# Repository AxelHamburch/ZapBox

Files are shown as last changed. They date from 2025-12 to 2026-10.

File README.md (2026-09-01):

# Lightning - Zap⚡Box

> **Forked from [danielcharrua/satoffee](https://github.com/danielcharrua/satoffee)**
> Expanded with many new features and hardware for many new use cases.

**A Bitcoin Lightning-controlled switching unit.** Pay an invoice — a relay switches. That's the core idea, and everything else is built on it: vending machines, tip boxes, kiosk terminals, coffee machines, LED signs, servo dispensers.

Ease of use, verifiability and reliability are paramount — all in one package.

📖 Detailed descriptions, images and application examples: [zapbox.space](https://zapbox.space/) · [ereignishorizont.xyz](https://ereignishorizont.xyz/en/zapbox-en/) · [white paper](https://github.com/AxelHamburch/ZapBox/tree/main/assets/white-paper)

---

## Table of Contents

- [How it Works](#how-it-works)
- [Which Variant Do I Need?](#which-variant-do-i-need)
- [Feature Matrix](#feature-matrix)
- [Quick Start](#quick-start)
- [Documentation](#documentation)
- [Development](#development)
- [Compatibility](#compatibility)
- [Acknowledgement](#acknowledgement)
- [Support](#support)

---

## How it Works

1. **QR code** — the display shows a QR code containing the LNURL *(display variants)*
2. **Lightning payment** — the customer scans and pays. Or they tap an **NFC Bolt Card** on the reader, or hold a **smartphone** near the NFC tag — all three routes work
3. **WebSocket trigger** — the LNbits server pushes the payment confirmation to the ESP32
4. **Relay switches** — the output is activated for the configured duration (optionally blinking, pulsing or strobing)
5. **Confirmation** — the display shows the payment was received *(display variants)*

The ZapBox never handles funds itself. It only listens for a confirmation from **your** LNbits server and switches a pin.

---

## Which Variant Do I Need?

Four hardware variants share the same firmware codebase. Pick by **how the customer interacts** with the device:

### 🖥️ [T-Display-S3](docs/t-display-s3.md) — the classic

Small integrated display (170 × 320), optional touch. The most widely deployed ZapBox and the best starting point for most builds.
**4 relay channels** · 2 buttons · optional servo mode · ~150–250 mA

*→ General retail, vending machines, coffee machines, tip boxes*

### 📱 [Touch 3.5"](docs/touch-3.5.md) — the big one

Large 3.5" capacitive touch display (480 × 320). The only variant with a **Mini-PoS mode** (customer-facing amount entry) and a **battery gauge**.
**6 flex channels** · vending sensors · LiPo battery support · ~200–350 mA

*→ Kiosk terminals, market stalls, flea markets, club bars, public vending installations*

### 💡 [Headless ESP32](docs/headless-esp32.md) — the workhorse

No display — status is signalled by a single LED with distinct blink patterns. Has by far the **most channels**.
**12 relay channels** · 2 vending sensors · ~100–150 mA

*→ Embedded and hidden installations, wall-mounted relay control, multi-channel dispensers*

### ⚡ [ESP32-C3](docs/esp32-c3.md) — the small one

Single-core RISC-V, the smallest footprint and the lowest power draw of all variants.
**1 relay + 2 flex channels** · ~80–120 mA

*→ Extremely tight spaces, battery-powered installs, cost-sensitive volume deployments*

---

## Feature Matrix

| | T-Display-S3 | Touch 3.5" | Headless ESP32 | ESP32-C3 |
|---|---|---|---|---|
| **Processor** | ESP32-S3 dual-core | ESP32-S3 dual-core | ESP32 dual-core | ESP32-C3 single-core RISC-V |
| **Display** | LCD 170×320 | Touch 480×320 | — | — |
| **Memory** | 16 MB / 8 MB PSRAM | 16 MB / 8 MB PSRAM | 4 MB / 512 KB | 4 MB / 400 KB |
| **Relay channels** | 4 | 6 | **12** | 1 (+2 flex) |
| **I/O Expander** (+8 channels) | ✅ | — | ✅ | — |
| **Servo mode** | ✅ | ✅ per channel | ✅ | ✅ |
| **Vending sensors** | 1 (light barrier) | 3 | 2 | 2 |
| **NFC** (Bolt Card, phone tap) | ✅ | ✅ | ✅ | ✅ |
| **Identity🫆Login** | LNURL-auth + NFC | LNURL-auth + NFC + PIN | NFC only | — |
| **Mini-PoS** (amount entry) | — | ✅ | — | — |
| **Battery gauge** | — | ✅ | — | — |
| **BTC ticker** | ✅ | ✅ | — | — |
| **Screensaver / Deep Sleep** | ✅ | ✅ | ✅ | ✅ |
| **Power draw** | ~150–250 mA | ~200–350 mA | ~100–150 mA | ~80–120 mA |
| **Firmware suffix** | *(none)* | `t` | `h` | `c` |

---

## Quick Start

1. **Build the hardware** — follow the [electrical layout](docs/hardware-assets.md#electrical-layouts) for your variant
2. **Set up LNbits** — you need a server with the [bitcoinswitch](https://github.com/lnbits/bitcoinswitch) or [zapbox](https://github.com/AxelHamburch/zapbox_extension) extension, and a switch entry per channel
3. **Flash and configure** — open the Web Installer in Chrome or Edge, flash the firmware, then enter WiFi and LNbits settings over the same serial connection

| Variant | Web Installer |
|---|---|
| T-Display-S3 | [installer.zapbox.space](https://installer.zapbox.space/) |
| Touch 3.5" | [installer.zapbox.space/touch3.5/](https://installer.zapbox.space/touch3.5/) |
| Headless ESP32 | [installer.zapbox.space/headless/](https://installer.zapbox.space/headless/) |
| ESP32-C3 | [installer.zapbox.space/c3/](https://installer.zapbox.space/c3/) |

**Entering config mode on an already-flashed device:** hold the BOOT button for 5 seconds.

---

## Documentation

### Hardware variants — pin maps, channels, board-specific features

- 🖥️ **[T-Display-S3](docs/t-display-s3.md)** — GPIO map, 4 channels, servo mode, ambient lighting, light barrier
- 📱 **[Touch 3.5"](docs/touch-3.5.md)** — GPIO map, 6 flex channels, Mini-PoS, battery gauge, vending sensors
- 💡 **[Headless ESP32](docs/headless-esp32.md)** — GPIO map, 12 channels, LED diagnostics, vending sensors
- ⚡ **[ESP32-C3](docs/esp32-c3.md)** — GPIO map, relay + flex channels

### Features across all variants

- 🔧 **[Common Features](docs/common-features.md)** — special modes, BTC ticker, threshold mode, I/O expander, LED button, screensaver & deep sleep, startup & error diagnostics
- 📡 **[NFC](docs/nfc.md)** — Bolt Card payments, card emulation, NT3H2111 phone tap
- 🫆 **[Identity🫆Login](docs/identity.md)** — LNURL-auth and NTAG 424 DNA login without payment

### Hardware & documents

- 🛠️ **[Housings, Layouts & Manuals](docs/hardware-assets.md)** — 3D models, wiring diagrams, operating instructions, QA protocols
- 📦 **[Firmware Release Process](FIRMWARE.md)** — how releases are built

---

## Development

PlatformIO project, Arduino framework, ESP32.

```bash
pio run -e lilygo-t-display-s3    # T-Display-S3
pio run -e Touch3_5               # Touch 3.5"
pio run -e esp32dev               # Headless
pio run -e esp32-c3-21-1          # ESP32-C3
```

**Libraries:** ArduinoJson · OneButton · WebSockets · TFT_eSPI · QRCode

<details>
<summary><strong>Project structure</strong></summary>

```
ZapBox/
├── src/                           # Firmware source (C++)
│   ├── main.cpp                   # Entry point and main event loop
│   ├── API.cpp/h                  # LNbits API & Bitcoin ticker
│   ├── Battery.cpp/h              # Battery gauge (Touch 3.5")
│   ├── Display.cpp/h              # Display rendering (T-Display-S3)
│   ├── DisplayTouch.cpp           # Display rendering (Touch 3.5")
│   ├── DisplayStubs.cpp           # No-op display layer (headless)
│   ├── GlobalState.cpp/h          # Global state & configuration
│   ├── Input.cpp/h                # Button & touch input
│   ├── Navigation.cpp/h           # Screen navigation
│   ├── Network.cpp/h              # WiFi & WebSocket
│   ├── Payment.cpp/h              # Payment processing & LNURL encoding
│   ├── UI.cpp/h                   # UI components
│   ├── NFCPN532.cpp/h             # PN532 NFC reader driver
│   ├── NFCBoltCard.cpp/h          # Bolt Card LNURLW authentication
│   ├── NFCCardEmulation.cpp/h     # PN532 target mode
│   ├── NFCNT3H2111.cpp/h          # NT3H2111 NFC Tag 2 driver
│   ├── IOExpander.h               # PCF8574 (pins 200–207) + PCF8575 (pins 300–315)
│   ├── I2CBus.h                   # Shared I²C bus mutex
│   ├── ServoControl.cpp/h         # Servo motor control
│   ├── TouchCST816S.cpp/h         # Touch driver (T-Display-S3)
│   ├── TouchAXS15231B.cpp/h       # Touch driver (Touch 3.5")
│   ├── SerialConfig.cpp/h         # Serial configuration interface
│   └── PinConfig.h                # Hardware pin definitions (all boards)
├── docs/                          # Documentation (you are here)
├── installer/                     # Web installer & firmware binaries
├── assets/                        # Housings, layouts, manuals, QA
└── platformio.ini                 # Build configuration
```

</details>

---

## Compatibility

- **LNbits**: v1.4.x or higher
- **Bitcoin Switch Extension**: v1.2.1 or higher
- **ZapBox Extension**: required for NFC Bolt Card payments and Mini-PoS — **v2.6.2 or higher** for current firmware (Bolt Card taps and PIN entry ride a persistent device channel; older extensions are served via HTTPS fallback, but the 2.6.0/2.6.1 intermediates must not be mixed with newer firmware)
- **ESP32 classic**: a standard ESP32 works for the headless build — an **unsoldered 30-pin board** is recommended for the headless housing

Software versioning follows the [Releases](https://github.com/AxelHamburch/ZapBox/releases). Housings (`b…`) and electrical layouts (`e…`) are versioned by Bitcoin block height — see [Hardware & Documents](docs/hardware-assets.md).

---

## Acknowledgement

This project is based on Daniel's [SATOFFEE](https://github.com/danielcharrua/satoffee) and uses parts from Ben's [bitcoinswitch](https://github.com/lnbits/bitcoinswitch).

A big thank you goes to [Ben Arc](https://njump.to/nprofile1qqsvrlrhw86l5sv06wkyjgs6rrcekskvk7nx8k50qn9m7mqgeqxjpvgpzamhxue69uhhyetvv9ujumn0wd68ytnzv9hxgtctcf224) and the entire LNbits team for their incredible work.

Parts of this project were developed with the assistance of AI coding assistants (**GitHub Copilot** and **Claude**).

---

## Support

This is a free and open source project. Support is welcome. Making Bitcoin Lightning technology ⚡ accessible to everyone — worldwide. 🌍

<table>
<tr>
<td>
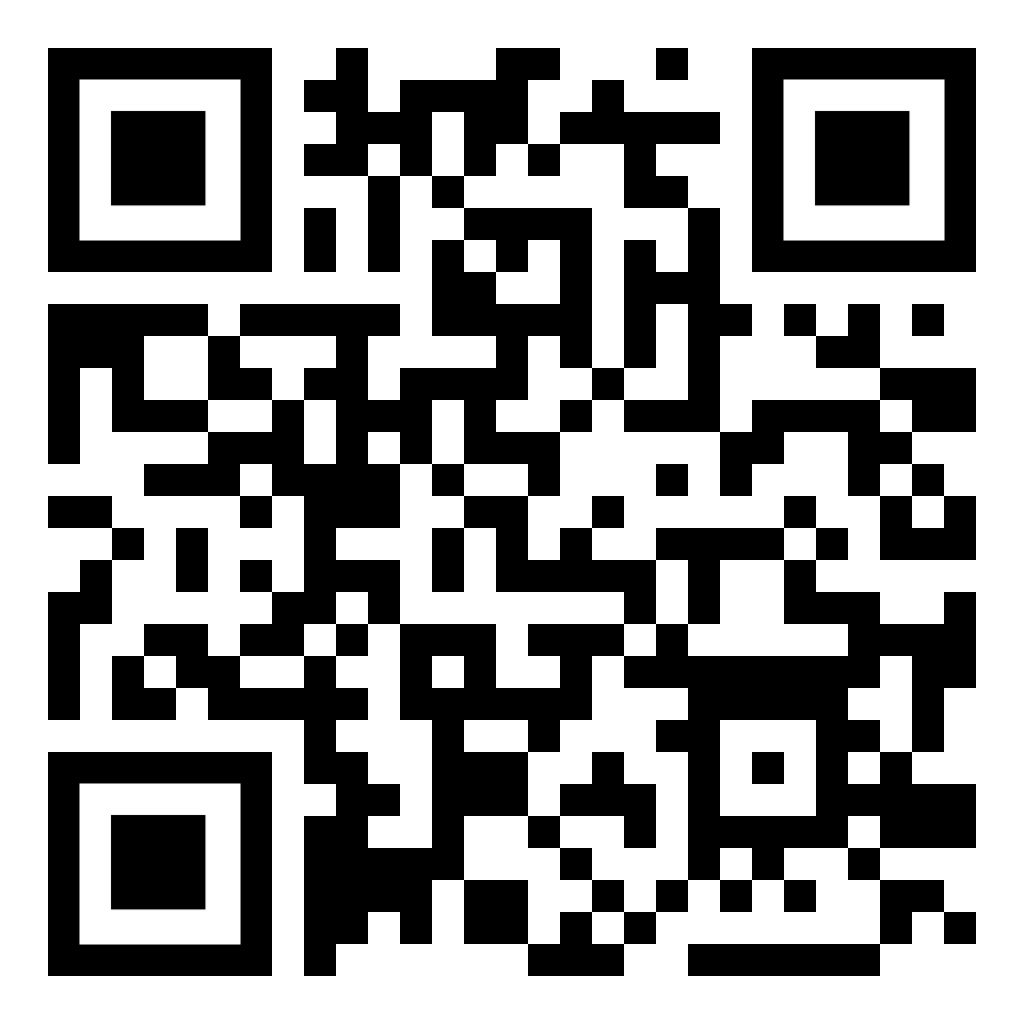
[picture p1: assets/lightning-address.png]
Lightning Address QR Code

</td>
<td>
Lightning⚡Address<br>
axelhamburch@ereignishorizont.xyz
</td>
</tr>
</table>

---

**Lightning ZapBox** — Compact, simple, Bitcoin-powered! ⚡

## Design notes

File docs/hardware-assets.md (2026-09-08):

# Hardware, Housings & Documents

Everything that is not firmware: 3D-printed housings, electrical layouts, operating instructions and QA protocols.

Software versioning follows the [Releases](https://github.com/AxelHamburch/ZapBox/releases). Housings (`b…`) and electrical layouts (`e…`) are versioned by **Bitcoin block height** in the same way.

---

## Table of Contents

- [Electrical Layouts](#electrical-layouts)
- [Housing / 3D Models](#housing--3d-models)
- [Operating Instructions](#operating-instructions)
- [Quality Assurance](#quality-assurance)

---

## Electrical Layouts

Complete wiring diagrams — start here when building a ZapBox.

| Variant | Diagram |
|---|---|
| **Simple** | [E-Layout-ZapBox-Simple.png](../assets/electric/E-Layout-ZapBox-Simple.webp) |
| **Compact** | [E-Layout-ZapBox-Compact.png](../assets/electric/E-Layout-ZapBox-Compact.png) |
| **Compact-Ext** | [E-Layout-ZapBox-Compact-Ext.png](../assets/electric/E-Layout-ZapBox-Compact-Ext.png) |
| **Duo** | [E-Layout-ZapBox-Duo.png](../assets/electric/E-Layout-ZapBox-Duo.png) |
| **Quattro** | [E-Layout-ZapBox-Quattro.png](../assets/electric/E-Layout-ZapBox-Quattro.png) |
| **ZapOMat** | [E-Layout-ZapBox-ZapOMat.png](../assets/electric/E-Layout-ZapBox-ZapOMat.png) |
| **Servo** | [E-Layout-ZapBox-Servo.png](../assets/electric/E-Layout-ZapBox-Servo.png) |
| **Touch 3.5" — ONE** | [E-Layout-ZapBox-Touch3.5-ONE.webp](../assets/electric/E-Layout-ZapBox-Touch3.5-ONE.webp) |
| **Touch 3.5" — FOUR** | [E-Layout-ZapBox-Touch3.5-FOUR.webp](../assets/electric/E-Layout-ZapBox-Touch3.5-FOUR.webp) |
| **Touch 3.5" — SIX+** | [E-Layout-ZapBox-Touch3.5-SIX+.webp](../assets/electric/E-Layout-ZapBox-Touch3.5-SIX+.webp) |
| **Headless** | [E-Layout-ZapBox-Headless.png](../assets/electric/E-Layout-ZapBox-Headless.png) |
| **Headless (S)imple** | [E-Layout-ZapBox-Headless-S.webp](../assets/electric/E-Layout-ZapBox-Headless-S.webp) |
| **Headless Servo** | [E-Layout-ZapBox-Headless-Servo.png](../assets/electric/E-Layout-ZapBox-Headless-Servo.png) |
| **ESP32-C3-21-1** | [E-Layout-ZapBox-esp32-c3-21-1.png](../assets/electric/E-Layout-ZapBox-esp32-c3-21-1.png) |

**Miscellaneous:** [ZapSave](../assets/electric/E-Layout-ZapBox-ZapSave.png) · [USB-Power-Hub](../assets/electric/E-Layout-ZapBox-USB-Power-Hub.png)

### Version history (Inkscape)

| Version | Type | Comment |
|---|---|---|
| e926834 | Compact | Prototype |
| e928304 | Compact | Prototype 2 |
| e928556 | Compact | Sample device |
| e931557 | Duo | First Duo |
| e932547 | Quattro | First Quattro |
| e932714 | Duo | Duo update |
| e935776 | Headless | First Headless |
| e932547 | Quattro | Add update button cable & IR light barrier |
| e937540 | Duo | Duo update |
| e937544 | USB-Power-Hub | First USB-Power-Hub |
| e938714 | ZapOMat | First ZapOMat design |
| e938889 | Headless | Update Headless with ZapBox picture |
| e938897 | Compact | Update Compact with ZapBox picture |
| e939705 | ZapOMat | ZapOMat No.1 |
| e940540 | Headless | Update |
| e943674 | Servo | Start the Servo story |
| e944644 | Headless Servo | First powerful Headless Servo |
| e945370 | ZapOMat | Update with wide-range voltage input |
| e946465 | Servo | Update with wide-range voltage input and NFC plug |
| e947689 | Compact-Ext | Special version with external guided switching contact |
| e948960 | Headless Servo | Add NFC Tag 2 module |
| e948971 | Headless | Add NFC Tag 2 module |
| e949393 | esp32-c3-21-1 | Add special Hans Wurst version |
| e949674 | Servo | Add NFC Tag 2 module & minor redesign |
| e950677 | Compact | Add NFC Tag 2 module |
| e950939 | Touch3.5 | ESP32-S Touch3.5 (JC3248W535C) — prototype |
| e955640 | ZapSave | ZapSave — sample connection |
| e957556 | Touch3.5-FOUR | ZapBox Touch 3.5 with 4 channels |
| e957575 | Touch3.5-ONE | ZapBox Touch 3.5 with 1 channel |
| e958085 | Touch3.5-SIX+ | ZapBox Touch 3.5 with 6 channel & expansion options |
| e959848 | Simple | As simple as possible |
| e965965 | Headless S | First Headless (S)imple |

→ All versions: [assets/electric/](https://github.com/AxelHamburch/ZapBox/tree/main/assets/electric)

---

## Housing / 3D Models

Designed in **FreeCAD**, exported as `.3mf` for printing.

| Version | Type | Comment |
|---|---|---|
| b926837 | Compact | Prototype, uses e926834 |
| b928260 | Compact | Prototype 2, uses e928304 |
| b928555 | Compact | Sample device, uses e928556 |
| b930595 | Compact | Optimization, separate label |
| b931760 | Duo | Prototype Duo with two front panels, 90° and 35° |
| b932506 | Compact | Adapter system, 90° front, USB-C position changed |
| b932595 | Duo & Quattro | Prototype Quattro and Duo update, 90° and 35° front |
| b932788 | Illuminated Sign | Prototype LED sign for demonstration and testing |
| b935750 | Headless | Prototype Headless — ZapBox without display |
| b937454 | USB-Power-Hub | Prototype USB-Power-Hub — voltage distribution only |
| b939002 | Compact | Compact 35° with NFC cap |
| b939704 | ZapOMat | ZapOMat No.1 |
| b940298 | Duo | Update & NFC lid |
| b943400 | Headless | Headless with NFC |
| b943614 | Servo | The first one with servo control |
| b944177 | Headless | Mounting plate with snap-fit connection |
| b944666 | Headless Servo | First powerful Headless Servo |
| b945188 | ZapOMat | Mounting plate and wide-range voltage input |
| b946303 | Servo | Mounting plate and tweaks |
| b946400 | Compact | Mounting plate, 90° NFC and Ext. option |
| b948772 | Headless Servo | Add NFC Tag 2 module |
| b948929 | Headless | Add NFC Tag 2 module |
| b949639 | Servo | Add NFC Tag 2 module |
| b950530 | Compact | Add NFC Tag 2 module |
| b950711 | Touch 3.5 | ESP32-S Touch3.5 (JC3248W535C) No.1 — prototype |
| b955706 | ZapSave | ZapSave — sample box |
| b956540 | Touch3.5-FOUR | ZapBox Touch 3.5 with 4 channels — incl. battery holder |
| b957183 | Touch3.5-ONE | ZapBox Touch 3.5 with 1 channel — incl. battery holder |
| b958015 | Touch3.5-SIX+ | ZapBox Touch 3.5 with 6 channel & expansion options |
| b959898 | Simple | As simple as possible |
| b965887 | Headless S | First Headless (S)imple |

→ All versions: [assets/housing/](https://github.com/AxelHamburch/ZapBox/tree/main/assets/housing)

---

## Operating Instructions

User manuals in Markdown (for reading online) and PDF (for printing).

| | Markdown | PDF |
|---|---|-----|
| **Compact** | [de](../assets/operating-instructions/Compact-oi-de.md) / [en](../assets/operating-instructions/Compact-oi-en.md) | [de](../assets/operating-instructions/Compact-oi-de.pdf) / [en](../assets/operating-instructions/Compact-oi-en.pdf) |
| **Duo** | [de](../assets/operating-instructions/Duo-oi-de.md) / [en](../assets/operating-instructions/Duo-oi-en.md) | [de](../assets/operating-instructions/Duo-oi-de.pdf) / [en](../assets/operating-instructions/Duo-oi-en.pdf) |
| **Quattro** | [de](../assets/operating-instructions/Quattro-oi-de.md) / [en](../assets/operating-instructions/Quattro-oi-en.md) | [de](../assets/operating-instructions/Quattro-oi-de.pdf) / [en](../assets/operating-instructions/Quattro-oi-en.pdf) |
| **ZapOMat** | [de](../assets/operating-instructions/ZapOMat-oi-de.md) / [en](../assets/operating-instructions/ZapOMat-oi-en.md) | [de](../assets/operating-instructions/ZapOMat-oi-de.pdf) / [en](../assets/operating-instructions/ZapOMat-oi-en.pdf) |
| **Servo** | [de](../assets/operating-instructions/Servo-oi-de.md) / [en](../assets/operating-instructions/Servo-oi-en.md) | [de](../assets/operating-instructions/Servo-oi-de.pdf) / [en](../assets/operating-instructions/Servo-oi-en.pdf) |
| **Headless** | [de](../assets/operating-instructions/Headless-oi-de.md) / [en](../assets/operating-instructions/Headless-oi-en.md) | [de](../assets/operating-instructions/Headless-oi-de.pdf) / [en](../assets/operating-instructions/Headless-oi-en.pdf) |
| **Headless Servo** | [de](../assets/operating-instructions/Headless-Servo-oi-de.md) / [en](../assets/operating-instructions/Headless-Servo-oi-en.md) | [de](../assets/operating-instructions/Headless-Servo-oi-de.pdf) / [en](../assets/operating-instructions/Headless-Servo-oi-en.pdf) |

→ Archive and development: [assets/operating-instructions/](https://github.com/AxelHamburch/ZapBox/tree/main/assets/operating-instructions)

---

## Quality Assurance

Templates for QA protocols to ensure ZapBox build quality.

- [Initial Review (German)](../assets/QA/initial-review-de.md) — [PDF](../assets/QA/initial-review-de.pdf)
- [Initial Review (English)](../assets/QA/initial-review-en.md) — [PDF](../assets/QA/initial-review-en.pdf)

→ Archive and development: [assets/QA/](https://github.com/AxelHamburch/ZapBox/tree/main/assets/QA)

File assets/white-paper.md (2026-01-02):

# ZapBox White Paper

**Bitcoin Lightning Network-gesteuerte IoT-Gerätesteuerung**

Version 1.0 | Januar 2026

---

## Abstract

ZapBox ist eine Open-Source-Hardware- und Softwarelösung, die es ermöglicht, physische Geräte über das Bitcoin Lightning Network zu steuern. Durch die Kombination eines ESP32-Mikrocontrollers mit einem Display, Relais und einer WebSocket-basierten Backend-Infrastruktur schafft ZapBox eine Brücke zwischen Kryptowährungszahlungen und realer IoT-Gerätesteuerung. Dieses White Paper beschreibt die technische Architektur, Implementierungsdetails, Anwendungsfälle und die Vision hinter dem Projekt.

---

## Inhaltsverzeichnis

1. [Einleitung](#1-einleitung)
2. [Problemstellung](#2-problemstellung)
3. [Technische Architektur](#3-technische-architektur)
4. [Hardware-Spezifikationen](#4-hardware-spezifikationen)
5. [Backend-Infrastruktur](#5-backend-infrastruktur)
6. [Zahlungsablauf](#6-zahlungsablauf)
7. [Installation und Konfiguration](#7-installation-und-konfiguration)
8. [Betriebsmodi](#8-betriebsmodi)
9. [Sicherheit und Zuverlässigkeit](#9-sicherheit-und-zuverlässigkeit)
10. [Anwendungsfälle](#10-anwendungsfälle)
11. [Produktvarianten](#11-produktvarianten)
12. [Open-Source-Ökosystem](#12-open-source-ökosystem)
13. [Roadmap und Zukunftsperspektiven](#13-roadmap-und-zukunftsperspektiven)
14. [Fazit](#14-fazit)
15. [Referenzen](#15-referenzen)

---

## 1. Einleitung

Die Digitalisierung von Zahlungsprozessen hat in den letzten Jahren erhebliche Fortschritte gemacht. Das Bitcoin Lightning Network bietet als Layer-2-Lösung auf der Bitcoin-Blockchain die Möglichkeit, nahezu kostenfrei und in Echtzeit Mikrotransaktionen durchzuführen. ZapBox nutzt diese Technologie, um eine dezentrale, programmierbare Schnittstelle zwischen digitalen Zahlungen und physischer Gerätesteuerung zu schaffen.

### Vision

**"Wir möchten die Bitcoin-Lightning-Technologie ⚡ für alle zugänglich machen – weltweit. 🌍"**

ZapBox senkt die Einstiegshürden für die Nutzung von Bitcoin Lightning im Internet of Things (IoT) und ermöglicht es jedem – vom Hobbybastler bis zum professionellen Anwender – eigene Lightning-gesteuerte Anwendungen zu realisieren.

---

## 2. Problemstellung

Trotz des enormen Potenzials des Lightning Networks existieren mehrere Barrieren für dessen breite Adoption im IoT-Bereich:

- **Technische Komplexität**: Die Integration von Lightning-Zahlungen in Hardware-Projekte erfordert tiefgreifendes technisches Wissen
- **Fehlende Standardlösungen**: Es gibt wenige fertige Lösungen, die Hardware, Software und Backend integrieren
- **Zugänglichkeit**: Nicht-technische Nutzer können die Technologie nicht ohne weiteres nutzen
- **Hardware-Integration**: Die Verbindung zwischen Zahlungseingang und physischer Aktion ist komplex

ZapBox adressiert diese Herausforderungen durch eine vollständig integrierte, benutzerfreundliche Lösung.

---

## 3. Technische Architektur

### 3.1 Systemübersicht

```
┌─────────────────┐
│  Lightning      │
│  Wallet         │
│  (Nutzer)       │
└────────┬────────┘
         │ QR-Code Scan
         │ LNURL
         ▼
┌─────────────────┐
│  LNbits Server  │
│  + BitcoinSwitch│
│  Extension      │
└────────┬────────┘
         │ WebSocket
         ▼
┌─────────────────┐        ┌──────────────┐
│  ZapBox         │───────►│  Relais      │
│  (ESP32)        │        │  Steuerung   │
└─────────────────┘        └──────────────┘
         │                          │
         ▼                          ▼
┌─────────────────┐        ┌──────────────┐
│  Display        │        │  Externes    │
│  (QR-Code)      │        │  Gerät       │
└─────────────────┘        └──────────────┘
```

### 3.2 Komponenten

**Frontend (Hardware)**
- ESP32 Mikrocontroller
- Display (TFT)
- Touchscreen (CST816S)
- Relais-Modul
- Optionale NFC-Unterstützung (PN532)

**Backend (Software)**
- LNbits Server (Wallet & Account System)
- BitcoinSwitch Extension
- WebSocket-Server für Echtzeitkommunikation

**Kommunikation**
- WiFi (2.4 GHz)
- WebSocket-Protokoll
- LNURL-Standard

---

## 4. Hardware-Spezifikationen

### 4.1 Kern-Komponenten

**Mikrocontroller: ESP32**
- Dual-Core Prozessor (240 MHz)
- 520 KB SRAM
- WiFi 802.11 b/g/n
- Bluetooth (optional nutzbar)
- Geringe Stromaufnahme
- Deep-Sleep-Modus verfügbar

**Display**
- TFT-Display (verschiedene Größen)
- Kapazitiver Touchscreen
- Hochauflösende QR-Code-Darstellung
- Konfigurierbare Farbschemata

**Relais-Modul**
- Schaltspannung: bis 250V AC / 30V DC
- Schaltstrom: bis 10A
- Optionale USB-Buchse (5V)
- Galvanische Trennung

### 4.2 Physisches Design

Die Hardware ist in drei Hauptvarianten verfügbar:

- **ZapBox Compact**: Einzelrelais, kompakte Bauweise
- **ZapBox Duo**: Zwei Relais, davon ein Leistungsrelais mit externen Klemmen
- **ZapBox Quattro**: Vier Relais mit externen Anschlussklemmen für professionelle Anwendungen

Alle Varianten verfügen über:
- 3D-druckbare Gehäuse (FreeCAD-Dateien verfügbar)
- Elektrische Konstruktionsunterlagen
- Stücklisten mit Bezugsquellen

---

## 5. Backend-Infrastruktur

### 5.1 LNbits Server

LNbits ist ein Open-Source Lightning Network Wallet und Account System. Es bietet:

- Multi-User-Wallet-Verwaltung
- Erweiterbare Plugin-Architektur
- REST API
- WebSocket-Support
- Lightning Node Abstraktion

### 5.2 BitcoinSwitch Extension

Die BitcoinSwitch Extension erweitert LNbits um IoT-Steuerungsfunktionalitäten:

- **Device Management**: Verwaltung mehrerer ZapBox-Geräte
- **Invoice Generation**: Automatische Rechnungserstellung
- **WebSocket Bridge**: Echtzeitkommunikation mit Geräten
- **Event Tracking**: Protokollierung aller Schaltvorgänge
- **Multi-Channel Support**: Verwaltung mehrerer Ausgänge pro Gerät

### 5.3 Device String

Jede ZapBox wird durch einen eindeutigen "Device String" identifiziert, der:
- Die Verbindung zum LNbits-Server authentifiziert
- Das spezifische Gerät identifiziert
- Den zu steuernden Ausgang spezifiziert
- In der Firmware konfiguriert wird

---

## 6. Zahlungsablauf

### 6.1 LNURL-Protokoll

Der auf dem Display angezeigte QR-Code verwendet das LNURL-Protokoll (Lightning URL), einen Standard für Lightning Network Interaktionen. Der QR-Code enthält:

1. Server-URL des LNbits-Backends
2. Device-Identifikation
3. Kanal/Ausgangs-Spezifikation
4. Optionale Metadata (Produktname, Preis)

### 6.2 Transaktionsablauf

```
1. ZapBox zeigt QR-Code (LNURL)
   └─> Enthält: Server-URL + Device-ID + Channel

2. Nutzer scannt QR-Code mit Lightning Wallet
   └─> Wallet kontaktiert LNbits Server

3. LNbits prüft WebSocket-Verbindung zur ZapBox
   └─> Bestätigt Geräteverfügbarkeit

4. LNbits generiert Invoice
   └─> Sendet an Wallet mit Betrag & Beschreibung

5. Nutzer bestätigt Zahlung im Wallet
   └─> Lightning-Zahlung wird ausgeführt

6. LNbits bestätigt Zahlungseingang
   └─> Sendet Event über WebSocket an ZapBox

7. ZapBox empfängt Event
   └─> Schaltet Relais für definierte Dauer

8. Relais öffnet/schließt Stromkreis
   └─> Externes Gerät wird aktiviert
```

### 6.3 Timing und Performance

- **Zahlungsbestätigung**: < 1 Sekunde (Lightning)
- **Event-Übertragung**: < 100ms (WebSocket)
- **Relais-Reaktion**: < 50ms
- **Gesamtdauer (Scan bis Schaltung)**: ~1-2 Sekunden

---

## 7. Installation und Konfiguration

### 7.1 Web Installer

ZapBox verwendet einen browserbasierten Installer: **https://installer.zapbox.space/**

Vorteile:
- Keine Software-Installation notwendig
- Plattformunabhängig (Windows, macOS, Linux)
- Nutzt Web Serial API
- Visuelle Feedback während des Flash-Vorgangs

### 7.2 Installationsprozess

**Schritt 1: Firmware-Flash**
1. ZapBox via USB verbinden
2. Web Installer öffnen
3. Firmware-Version auswählen
4. "Flash" Button klicken
5. Warten auf Abschluss

**Schritt 2: Konfiguration**

Pflichtparameter:
- **SSID**: WiFi-Netzwerkname
- **Password**: WiFi-Passwort
- **Device String**: Von LNbits BitcoinSwitch Extension

Optionale Parameter:
- **Display Orientation**: 0°, 90°, 180°, 270°
- **Color Scheme**: Hintergrund- und Textfarben
- **Screensaver**: Aktivierung und Timeout
- **Deep Sleep**: Energiesparmodus
- **Special Modes**: Multi-Channel, Threshold, BTC-Ticker

### 7.3 Ersteinrichtung

Nach dem ersten Boot:
1. ZapBox startet im AP-Modus (falls keine WiFi-Konfiguration)
2. Nutzer verbindet sich mit ZapBox-Access-Point
3. Captive Portal öffnet sich automatisch
4. WiFi und Device-Einstellungen werden eingegeben
5. ZapBox speichert Konfiguration und startet neu
6. Verbindung zum konfigurierten WiFi und LNbits-Server

---

## 8. Betriebsmodi

### 8.1 Standard-Modus

Klassischer Bitcoin-Switch:
- Ein Relais
- Ein Preis pro Zahlung
- Feste Schaltdauer

### 8.2 Multi-Channel-Modus

Mehrere unabhängige Zahlungskanäle:
- Bis zu 4 verschiedene QR-Codes
- Unterschiedliche Preise
- Verschiedene Schaltdauern
- Individuelle Ausgänge

Anwendung: Verkaufsautomat mit mehreren Produkten

### 8.3 Threshold-Modus

Akkumulative Zahlungen:
- Sammelt Zahlungen bis Schwellwert erreicht
- Schaltet erst bei Erreichen des Threshold
- Anzeige des aktuellen Saldos
- Reset nach Schaltung

Anwendung: Crowdfunding-basierte Aktivierung

### 8.4 BTC-Ticker-Modus

Bitcoin-Preis-Display:
- Echtzeit BTC/USD (oder andere Fiat-Währungen)
- Optionale Zahlungsfunktion
- Screensaver mit wechselnden Informationen

Anwendung: Informationsdisplay mit optionaler Spendenfunktion

### 8.5 Special-Modus

Erweiterte Funktionen:
- NFC-Integration (LNURL-NFC-Karten)
- Custom Display-Layouts
- API-Endpunkte für externe Systeme
- Event-Logging

---

## 9. Sicherheit und Zuverlässigkeit

### 9.1 Sicherheitsaspekte

**Netzwerksicherheit**
- TLS/SSL-verschlüsselte WebSocket-Verbindung
- WPA2-geschütztes WiFi
- Keine privaten Schlüssel auf dem Gerät
- Device String als einzige Authentifizierung

**Zahlungssicherheit**
- Lightning Network native Sicherheit
- Atomare Transaktionen
- Keine Rückbuchungen
- Invoice-basiertes System

**Physische Sicherheit**
- Galvanisch getrennte Relais
- Überstromschutz (optional)
- Gehäuse-Design verhindert versehentlichen Zugriff

### 9.2 Zuverlässigkeit

**Fehlerbehandlung**
- Automatische WiFi-Reconnection
- WebSocket-Reconnection mit Backoff
- Watchdog-Timer
- Fehler-Logging auf Display

**Monitoring**
- Verbindungsstatus auf Display
- Letzte Transaktion sichtbar
- Fehler-Codes bei Problemen
- Optional: Remote-Monitoring über LNbits

**Wartung**
- OTA-Updates möglich (zukünftig)
- Config-Reset via Button
- Factory-Reset-Funktion
- Diagnose-Modus

---

## 10. Anwendungsfälle

### 10.1 Kommerzielle Anwendungen

**Verkaufsautomaten**
- Getränkeautomaten
- Snackautomaten
- Waschmaschinen/Trockner in Waschsalons
- Schließfächer

**Zugangskontrollen**
- Türöffner
- Parkplatzschranken
- Ladestationen (E-Bike, E-Scooter)
- Co-Working-Spaces

**Dienstleistungen**
- Luftpumpen an Tankstellen
- Staubsauger an Waschplätzen
- Massagesessel
- Duschen (Campingplätze, Strandbäder)

### 10.2 Bildung und Demonstration

**Workshops**
- Bitcoin-Lightning-Schulungen
- IoT-Entwicklung mit Micropayments
- Maker-Spaces und Hackerspaces

**Ausstellungen**
- Hands-on Lightning-Demonstrationen
- Bitcoin-Konferenzen
- Tech-Messen

### 10.3 Private Nutzung

**Smart Home**
- Lichtsteuerung (Gamification)
- Garagentoröffner für Gäste
- Heimautomation mit Bitcoin-Trigger

**Spiele und Challenges**
- Escape-Room-Rätsel
- Bitcoin-Trivia-Automaten
- Belohnungssysteme

### 10.4 Soziale Projekte

**Crowdfunding**
- Threshold-Modus für Gemeinschaftsprojekte
- Öffentliche Kunstinstallationen
- Charity-Events

**Dezentralisierung**
- P2P-Ressourcenteilung ohne zentrale Verwaltung
- Community-betriebene Infrastruktur

---

## 11. Produktvarianten

### 11.1 ZapBox Compact

**Zielgruppe**: Einsteiger, Hobbyisten

**Spezifikationen**:
- 1 Relais (10A)
- USB-Ausgang (5V/2A)
- Kompaktes Gehäuse
- Eingebaute Antenne
- Touch-Display

**Anwendungen**:
- USB-Gerätesteuerung
- Einzelne Schaltfunktion
- Demonstrationsprojekte

### 11.2 ZapBox Duo

**Zielgruppe**: Ambitionierte Anwender

**Spezifikationen**:
- 2 Relais
- 1 Standard-Relais (10A)
- 1 Leistungsrelais (16A) mit externen Klemmen
- Größeres Gehäuse
- Potentialfreie Kontakte

**Anwendungen**:
- Zwei unabhängige Schaltungen
- Direkte 230V-Schaltung (Leistungsrelais)
- Kombinierte Anwendungen

### 11.3 ZapBox Quattro

**Zielgruppe**: Professionelle Anwendungen

**Spezifikationen**:
- 4 Relais (je 10A)
- Alle Kontakte nach außen geführt
- Professionelle Schraubklemmen
- Robustes Gehäuse
- Optionale DIN-Rail-Montage

**Anwendungen**:
- Verkaufsautomaten
- Komplexe Steuerungen
- Industrielle Integration
- Multi-Produkt-Systeme

### 11.4 Vergleichstabelle

| Eigenschaft | Compact | Duo | Quattro |
|---|---|-----|---|
| Relais | 1 | 2 | 4 |
| Externe Klemmen | Nein | Ja (1x) | Ja (4x) |
| USB-Ausgang | Ja | Optional | Nein |
| Gehäusegröße | Klein | Mittel | Groß |
| Max. Schaltleistung | 2300W | 3680W | 9200W |
| Preissegment | Einstieg | Mittel | Profi |

---

## 12. Open-Source-Ökosystem

### 12.1 Lizenzierung

Alle Komponenten der ZapBox sind vollständig Open Source:

**Hardware**
- Elektrische Schaltpläne: CC BY-SA 4.0
- 3D-Modelle (FreeCAD): CC BY-SA 4.0
- PCB-Layouts: CERN OHL v2

**Software**
- Firmware: MIT License
- Web Installer: MIT License
- Dokumentation: CC BY-SA 4.0

### 12.2 Repository-Struktur

**GitHub Repository**: https://github.com/AxelHamburch/ZapBox

```
ZapBox/
├── src/                    # Firmware-Quellcode
├── assets/                 # Hardware-Designs
│   ├── electric/          # Schaltpläne
│   └── housing/           # Gehäuse-3D-Modelle
├── installer/             # Web Installer
├── lib/                   # Bibliotheken
├── docs/                  # Dokumentation
└── test/                  # Tests
```

### 12.3 Verwendete Open-Source-Projekte

**Backend**:
- **LNbits** (MIT): https://github.com/lnbits/lnbits
- **BitcoinSwitch Extension** (MIT): https://github.com/lnbits/bitcoinswitch_extension

**Firmware-Bibliotheken**:
- ESP32 Arduino Core
- TFT_eSPI (Display)
- ArduinoJson
- WebSocketsClient
- WiFiManager

### 12.4 Community-Beiträge

Das Projekt lebt von Community-Beiträgen:
- Bug Reports und Feature Requests über GitHub Issues
- Pull Requests für Verbesserungen
- Hardware-Varianten und Anpassungen
- Übersetzungen
- Dokumentation

---

## 13. Roadmap und Zukunftsperspektiven

### 13.1 Kurzfristige Ziele (Q1-Q2 2026)

**Firmware**
- OTA-Update-Funktionalität
- Erweiterte NFC-Unterstützung
- Verbesserte Energieverwaltung
- Lokale API für externe Integration

**Hardware**
- ZapBox Quattro Serienproduktion
- Industrielle Variante mit DIN-Rail
- Outdoor-Gehäuse (IP65)

**Software**
- Web Installer v2.0 mit erweiterten Features
- Mobile App für Geräteverwaltung
- Monitoring-Dashboard

### 13.2 Mittelfristige Ziele (Q3-Q4 2026)

**Erweiterungen**
- ZapBox Mini (ohne Display, nur NFC)
- ZapBox Pro (mit integriertem Lightning Node)
- Modular-System für individuelle Konfigurationen

**Integration**
- Home Assistant Integration
- MQTT-Broker-Support
- RESTful API für Third-Party-Apps

**Ökosystem**
- Marketplace für Custom Firmware
- Template-Bibliothek für Anwendungen
- Zertifizierungsprogramm für Partner

### 13.3 Langfristige Vision

**Globale Adoption**
- Entwicklungsländer: Micropayment-Infrastruktur
- Unbanked Populations: Finanzielle Inklusion
- Dezentrale Energiemärkte: P2P-Stromhandel

**Technische Innovation**
- Integration mit RGB Protocol
- Taproot Assets Support
- Lightning-native Smart Contracts

**Standardisierung**
- LNURL-Device-Protocol-Standard
- IoT-Payment-Framework
- Interoperabilität mit anderen Lightning-IoT-Geräten

---

## 14. Fazit

ZapBox repräsentiert einen bedeutenden Schritt in der Verbindung von Bitcoin Lightning Network und dem Internet of Things. Durch die Kombination von benutzerfreundlicher Hardware, robuster Software und einem vollständig Open-Source-Ansatz macht das Projekt Lightning-Zahlungen für physische Anwendungen zugänglich.

### Kernvorteile

1. **Zugänglichkeit**: Senkt technische Hürden drastisch
2. **Dezentralisierung**: Keine zentralen Intermediäre notwendig
3. **Kosten**: Mikrotransaktionen ohne signifikante Gebühren
4. **Geschwindigkeit**: Echtzeit-Zahlungen und -Reaktionen
5. **Open Source**: Vollständige Transparenz und Anpassbarkeit
6. **Skalierbarkeit**: Von Einzelgeräten bis zu großen Installationen

### Bedeutung für das Lightning-Ökosystem

ZapBox demonstriert das Potenzial von Lightning über reine Peer-to-Peer-Zahlungen hinaus. Die Ermöglichung von Machine-to-Machine-Payments und IoT-Integration öffnet neue Anwendungsfelder:

- **Circular Economy**: Bitcoin als natives Zahlungsmittel in automatisierten Systemen
- **Programmable Money**: Zahlungen, die automatisch Aktionen auslösen
- **Micropayment Infrastructure**: Grundlage für pay-per-use Geschäftsmodelle

### Aufruf zur Beteiligung

Das Projekt lädt jeden ein, Teil der Entwicklung zu werden:
- **Entwickler**: Tragen Sie zur Firmware und Software bei
- **Hardware-Designer**: Entwickeln Sie neue Varianten und Gehäuse
- **Anwender**: Teilen Sie Ihre Use Cases und Feedback
- **Unternehmen**: Integrieren Sie ZapBox in Ihre Produkte

**"Jeder soll die ZapBox selbst bauen können. Aber viele werden das gar nicht können oder wollen. Wir möchten die Bitcoin-Lightning-Technologie ⚡ für alle zugänglich machen – weltweit. 🌍"**

---

## 15. Referenzen

### Technische Spezifikationen

- **Lightning Network**: https://lightning.network/
- **LNURL Protocol**: https://github.com/lnurl/luds
- **ESP32 Datasheet**: https://www.espressif.com/en/products/socs/esp32
- **Bitcoin Switch (Ben Arc)**: Original Konzept und Inspiration

### Open-Source-Projekte

- **ZapBox GitHub**: https://github.com/AxelHamburch/ZapBox
- **LNbits**: https://github.com/lnbits/lnbits
- **BitcoinSwitch Extension**: https://github.com/lnbits/bitcoinswitch_extension

### Weiterführende Informationen

- **ZapBox Website**: https://zapbox.space/
- **Web Installer**: https://installer.zapbox.space/
- **Community Forum**: (In Entwicklung)
- **Documentation**: https://github.com/AxelHamburch/ZapBox/wiki

### Kontakt

- **GitHub**: https://github.com/AxelHamburch
- **Repository Issues**: https://github.com/AxelHamburch/ZapBox/issues
- **Email**: (Über GitHub-Profile)

---

## Anhang A: Technische Glossar

- **ESP32**: Mikrocontroller von Espressif mit WiFi und Bluetooth
- **Lightning Network**: Layer-2-Protokoll für schnelle Bitcoin-Transaktionen
- **LNURL**: Lightning URL Protocol für vereinfachte Interaktionen
- **Invoice**: Lightning-Rechnung für eine Zahlung
- **WebSocket**: Bidirektionales Kommunikationsprotokoll
- **Relais**: Elektromechanischer Schalter
- **OTA**: Over-The-Air (drahtlose Firmware-Updates)
- **FOSS**: Free and Open Source Software

---

## Anhang B: Elektrische Spezifikationen

### Relais-Spezifikationen

**Standard-Relais (Compact, Duo, Quattro)**
- Kontakttyp: SPDT (Single Pole Double Throw)
- Nennspannung: 250V AC / 30V DC
- Nennstrom: 10A
- Schaltleistung: 2500VA / 300W
- Lebensdauer: >100.000 Zyklen

**Leistungsrelais (Duo)**
- Kontakttyp: SPDT
- Nennspannung: 250V AC / 30V DC
- Nennstrom: 16A
- Schaltleistung: 4000VA / 480W
- Lebensdauer: >50.000 Zyklen

### Stromversorgung

- Eingangsspannung: 5V DC via USB-C
- Stromaufnahme: 150-500mA (je nach Display-Helligkeit)
- Deep Sleep: <10mA
- Empfohlenes Netzteil: 5V/2A

---

## Anhang C: Versionierung

**Firmware-Versionen**:
- v9.x.x: Aktuelle Hauptversion
- Semantische Versionierung (MAJOR.MINOR.PATCH)
- Release Notes im GitHub Repository

**Hardware-Revisionen**:
- Elektrische Schemata: eXXXXXX-compact
- Gehäuse: bXXXXXX-compact
- Vollständige History in Git

---

*Dieses Dokument wurde am 2. Januar 2026 erstellt und wird regelmäßig aktualisiert. Die neueste Version ist stets im GitHub-Repository verfügbar.*

---

**ZapBox - Open Source Bitcoin Lightning IoT**

⚡ Powered by the Lightning Network | 🌍 Available Worldwide | 🔓 Fully Open Source

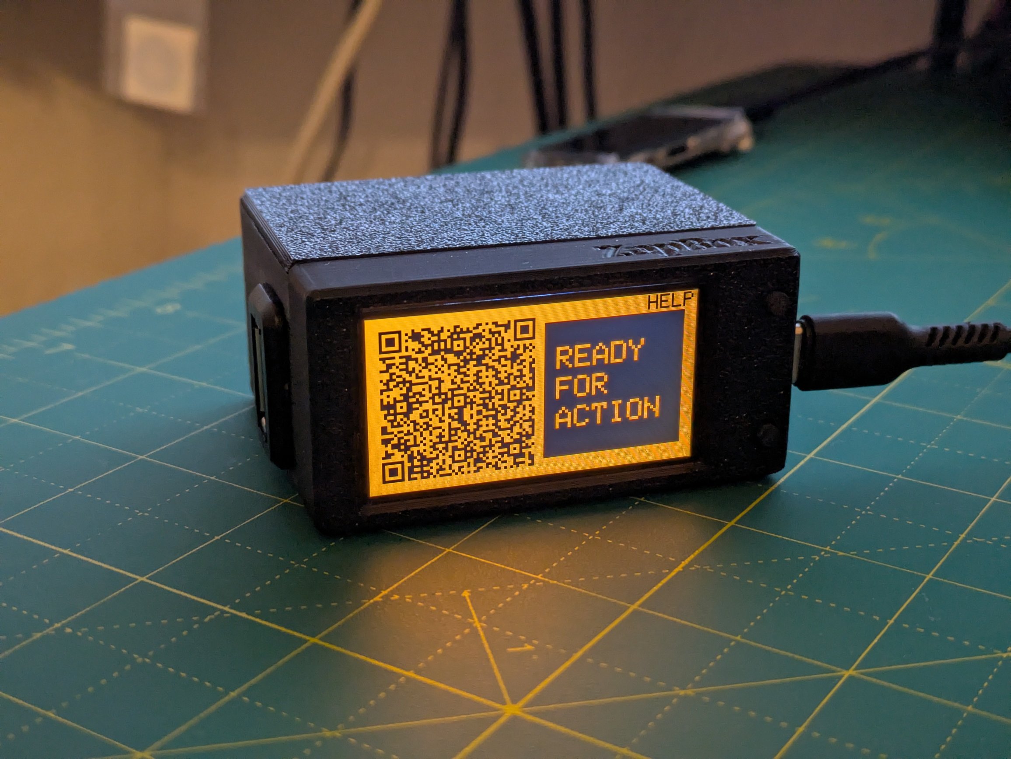
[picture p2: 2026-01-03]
assets/white-paper/ZapBox_no001.jpg

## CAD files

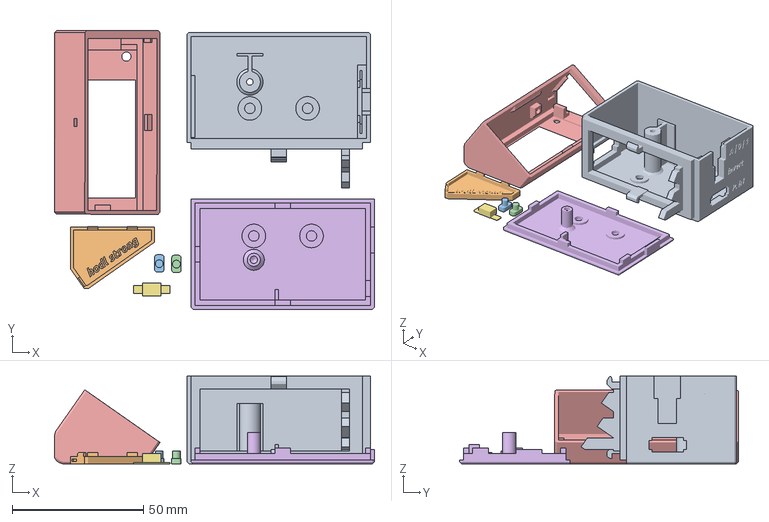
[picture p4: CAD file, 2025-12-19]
assets/housing/b928260-ompact/ZapBox Compact - b928260 full.3mf
122.0 x 106.3 x 33.5 mm

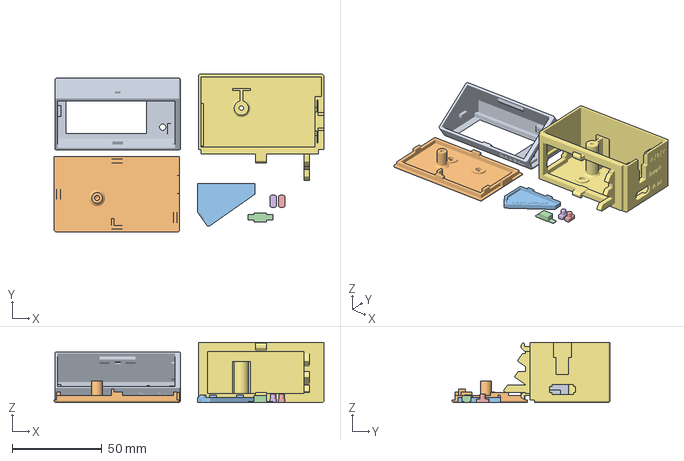
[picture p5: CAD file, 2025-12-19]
assets/housing/b928555-ompact/ZapBox Compact - b928555-full.3mf
150.3 x 87.9 x 33.5 mm

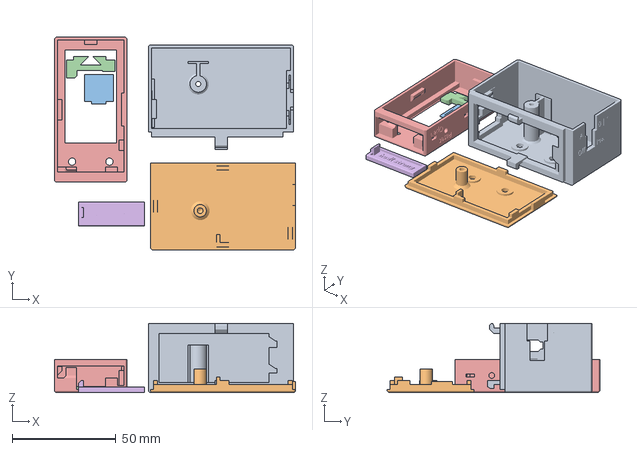
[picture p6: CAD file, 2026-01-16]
assets/housing/b932506-Compact/ZapBox Compact - b932506 - full - 90 degree.3mf
116.3 x 102.7 x 33.5 mm

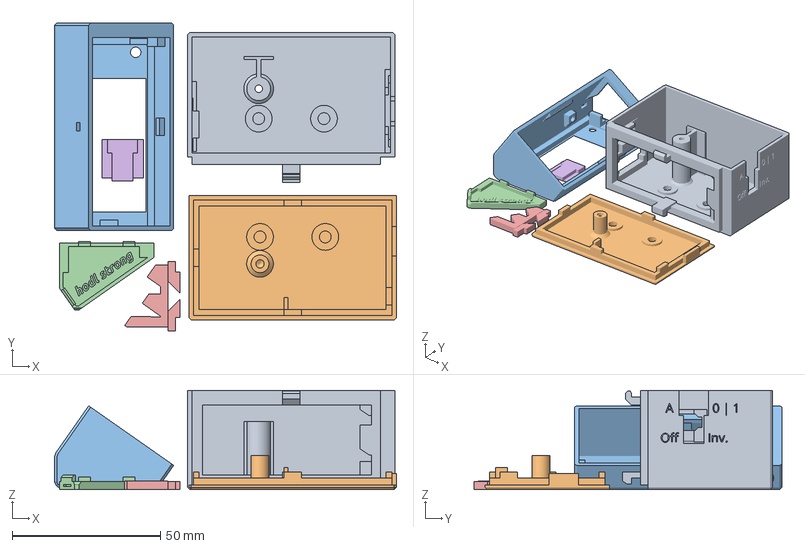
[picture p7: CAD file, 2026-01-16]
assets/housing/b932506-Compact/ZapBox Compact - b932506 - full - 35 degree.3mf
115.3 x 103.9 x 33.5 mm

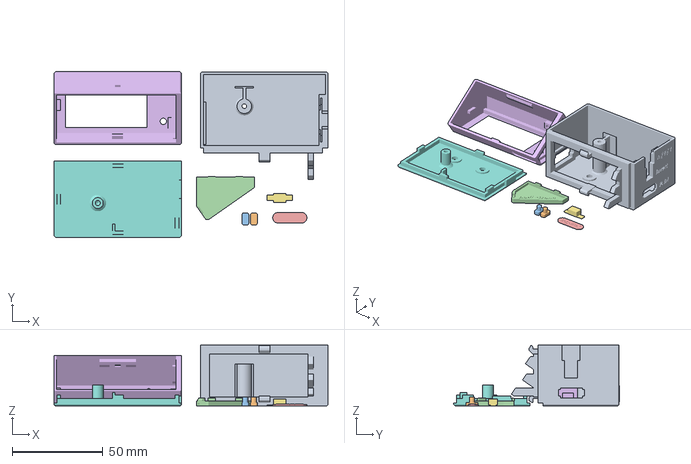
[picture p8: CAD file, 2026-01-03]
assets/housing/b930595-ompact/ZapBox Compact - b930595-Full.3mf
150.6 x 91.2 x 33.5 mm

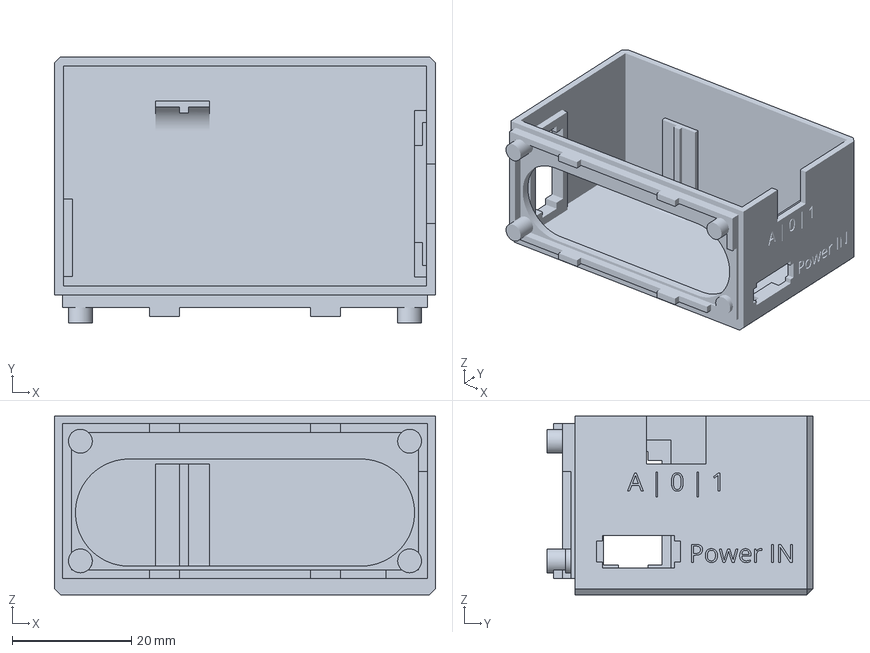
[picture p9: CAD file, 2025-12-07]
assets/housing/b926837-Compact/ZapBox Compact - v0.07-Grundkörper.3mf
64.0 x 44.7 x 30.0 mm

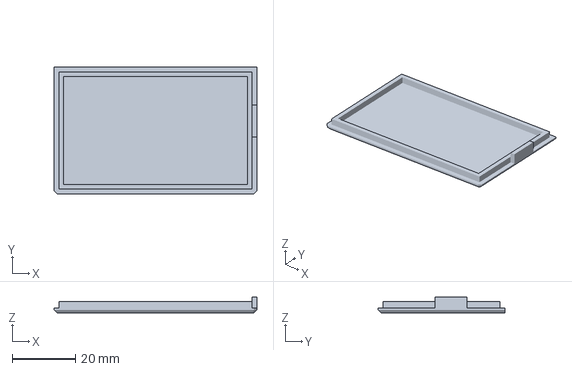
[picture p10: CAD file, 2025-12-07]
assets/housing/b926837-ompact/ZapBox Compact - v0.07-Deckel.3mf
64.0 x 40.0 x 5.00 mm

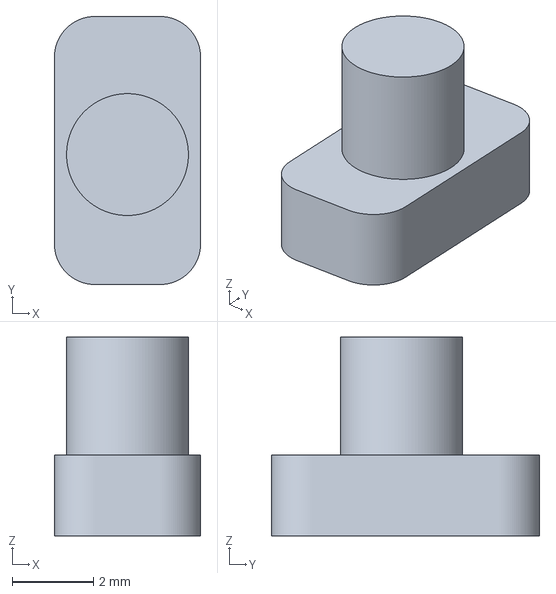
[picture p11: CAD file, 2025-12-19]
assets/housing/b928260-Compact/ZapBox Compact - b928260-Button (Solid).3mf
3.60 x 6.60 x 4.90 mm

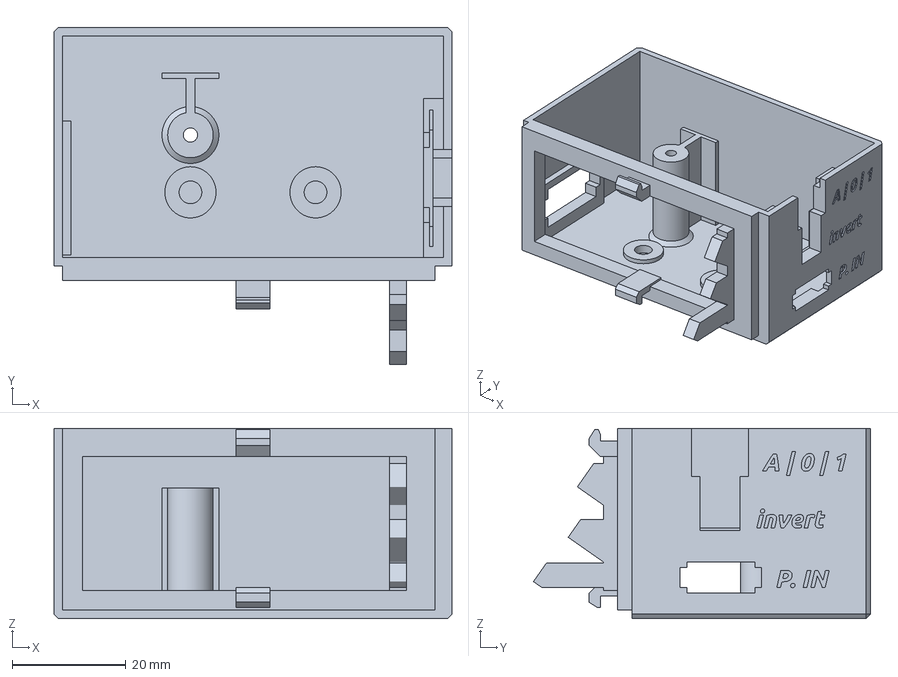
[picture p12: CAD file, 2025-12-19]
assets/housing/b928555-Compact/ZapBox Compact - b928555-Chamfer025 Chamber.3mf
70.0 x 59.3 x 33.5 mm

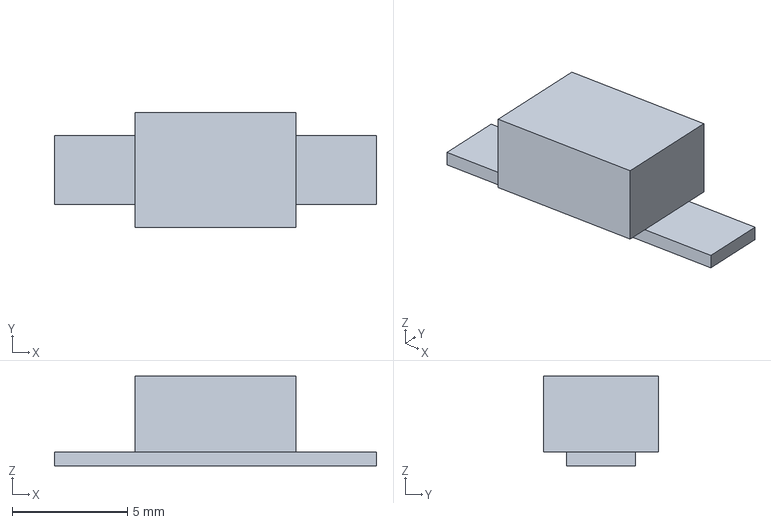
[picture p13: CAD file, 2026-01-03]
assets/housing/b930595-ompact/ZapBox Compact - b930595-Switch Spacer (Solid).3mf
14.0 x 5.00 x 3.90 mm

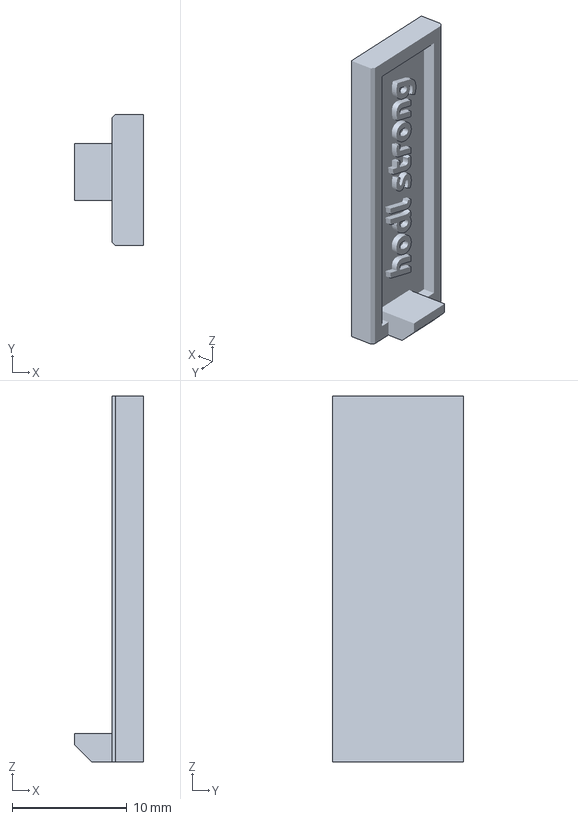
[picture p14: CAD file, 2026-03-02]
assets/housing/b939002-Compact/ZapBox Compact - b939002-Panel 90 degree.3mf
6.00 x 11.4 x 31.9 mm

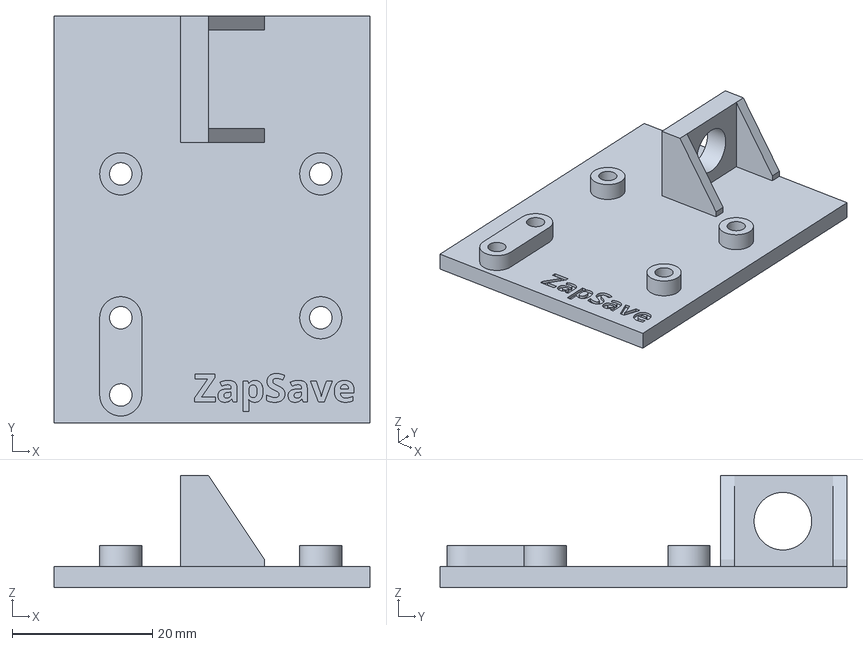
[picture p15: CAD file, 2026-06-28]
assets/housing/b955706-ZapSave/ZapSave - b955706-Circuit board.3mf
45.0 x 58.0 x 16.0 mm

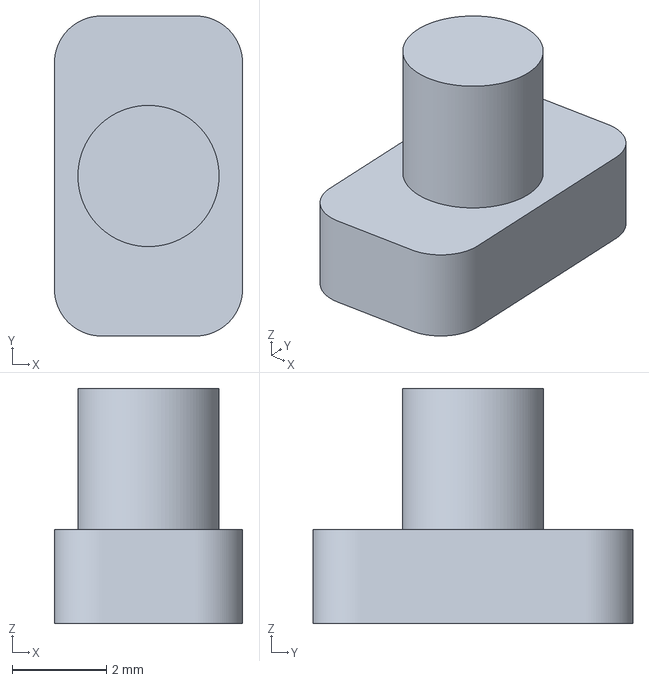
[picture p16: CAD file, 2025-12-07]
assets/housing/b926837-ompact/ZapBox Compact - v0.07-Taste.3mf
4.00 x 6.80 x 5.00 mm

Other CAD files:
assets/housing/b930595-Compact/ZapBox Compact - b930595-Chamfer Chamber.3mf
assets/housing/b926837-Compact/ZapBox Compact - v0.07-Front.3mf
assets/housing/b926837-ompact/ZapBox Compact - v0.07-Front.3mf
assets/housing/b928260-Compact/ZapBox Compact - b928260-Access Panel (Solid).3mf
assets/housing/b928260-Compact/ZapBox Compact - b928260-Chamfer Chamber.3mf
assets/housing/b928260-Compact/ZapBox Compact - b928260-Chamfer Front.3mf
assets/housing/b928260-Compact/ZapBox Compact - b928260-Chamfer Lid.3mf
assets/housing/b928260-Compact/ZapBox Compact - b928260-Switch Spacer (Solid).3mf
assets/housing/b928260-ompact/ZapBox Compact - b928260-Access Panel (Solid).3mf
assets/housing/b928260-ompact/ZapBox Compact - b928260-Chamfer Chamber.3mf
assets/housing/b928260-ompact/ZapBox Compact - b928260-Chamfer Front.3mf
assets/housing/b928260-ompact/ZapBox Compact - b928260-Chamfer Lid.3mf
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

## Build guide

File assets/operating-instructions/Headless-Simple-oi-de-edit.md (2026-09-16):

# ZapBox Headless Simple – Bedienungsanleitung

**Sprache:** Deutsch | **Version:** oi967253
---
## Inhaltsverzeichnis

1. [Übersicht](#übersicht)
2. [Ansichten](#ansichten)
3. [Anschlüsse](#anschlüsse)
4. [Bedienelemente](#bedienelemente)
5. [Einrichtung und Inbetriebnahme](#einrichtung-und-inbetriebnahme)
6. [Technische Daten](#technische-daten)
7. [Sicherheitshinweise](#sicherheitshinweise)
8. [Weiterführende Links](#weiterführende-links)

---

## Übersicht

Die **ZapBox Headless Simple** ist ein elektronischer Schalter für Bitcoin-Lightning-Zahlungen ohne Display. Mit einer Zahlung über das Lightning-Netzwerk lässt sich ein Ausgang schalten – ideal für eingebettete Anwendungen, verdeckte Installationen, Maschinenbau und überall dort, wo kein Display benötigt wird.

Der Betriebszustand wird ausschließlich über eine **Status-LED** angezeigt. Eine zweite **Action-LED** zeigt die Schaltfunktion an.

### Grundausstattung

| Komponente | Beschreibung |
|---|---|
| Mikrocontroller | ESP32 Dev Module (kein Display) |
| Eingang | Dual USB-A und USB-C |
| Ausgang | Dual USB-A und USB-C |
| Statusanzeige | Status-LED mit Blinkmustern und Action-LED als Rückmeldung |
| Bedienelement | Mikrotaster für BOOT (Config-Modus) und Reset |

## Ansichten

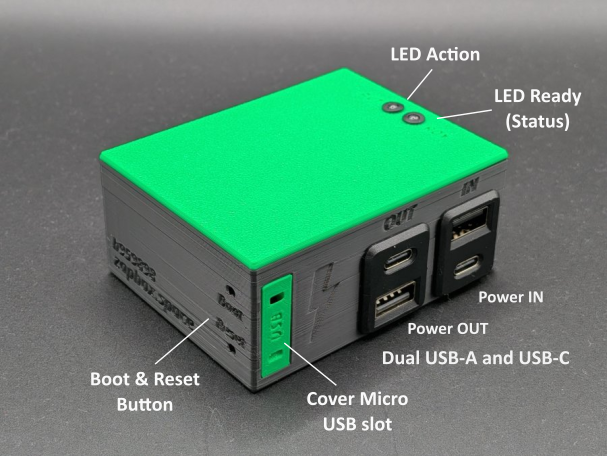
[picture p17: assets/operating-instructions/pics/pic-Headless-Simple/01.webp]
Dreiseitenansicht


*Bild 1: Dreiseitenansicht*

---

## Anschlüsse

### Eingang - Dual USB-A und USB-C Buchse zur Spannungsversorgung (5V)

Versorgen Sie das Gerät über den Anschluss **Power IN** mit einem USB-C-Kabel mit **5 V DC (max. 5 A)**.

> **Hinweis:** Der USB-Power-Anschluss unterstützt keine automatische USB-C-Leistungsanforderung (kein USB-C Power Delivery). Einige USB-C-Ladegeräte oder Powermodule erkennen die ZapBox daher nicht als Verbraucher und liefern keinen Strom. Verwenden Sie in diesem Fall einen **USB-A-Ausgang** der Spannungsversorgung oder eine alternative 5-V-Stromquelle. Die maximale Stromstärke darf 3 A nicht überschreiten.

### Eingang - Micro-USB Buchse am Mikrocontroller (Datenzugang, seitlich)

Um Daten vom Gerät zu lesen oder zu übertragen, verbinden Sie die ZapBox mit einem Computer oder Laptop:

1. An der **rechten Seite**, neben den USB-Anschlüssen, befindet sich ein kleines Panel. Öffnen Sie das Panel mit einem **schmalen Schraubendreher**, indem Sie es vorsichtig herausheben.
2. Schließen Sie ein Micro-USB-Kabel an den Mikrocontroller an.

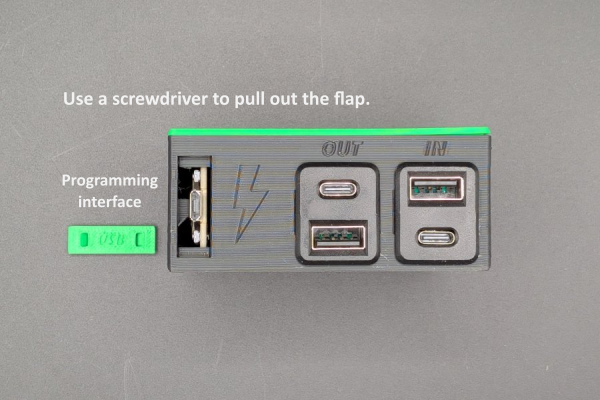
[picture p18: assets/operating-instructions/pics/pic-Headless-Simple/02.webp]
Micro USB Port


*Bild 2: Micro USB Port*

> **Wichtiger Hinweis:** Der USB-Anschluss direkt am Mikrocontroller ist ausschließlich zum Flashen der Firmware und zur Übertragung von Konfigurationsparametern vorgesehen. Während des Flashvorgangs darf keine Last am Ausgang angeschlossen oder geschaltet werden, da dies zu Fehlfunktionen oder zur **Beschädigung des Mikrocontrollers** führen kann.
>
> Es wird daher empfohlen:
> - während der USB-Verbindung keine Last am Ausgang anzuschließen oder
> - den regulären **Power-IN-Eingang** zusätzlich an dieselbe Spannungsversorgung anzuschließen. Dadurch wird sichergestellt, dass der Strom für das Leistungsrelais nicht über den Mikrocontroller fließt und diesen überlastet.

### Ausgang - Dual USB-A und USB-C Buchse (geschaltete 5V Spannung)

Die USB-Buchse wird über einen Relais-Schaltkontakt geschaltet. Die **Gesamtbelastung** der Buchsen sollte **3 A nicht überschreiten**.

---

## Bedienelemente

Die ZapBox Headless hat **kein Display**. Der Betriebszustand wird ausschließlich über die **Status-LED** (GPIO 21 (extern) / GPIO 2 (onboard)) und **Action-LED** (GPIO 13) signalisiert.

### Status-LED – Blinkmuster

| Muster | Bedeutung |
|---|---|
| 3× kurzes Blinken beim Start | Boot abgeschlossen |
| Schnelles Blinken | Verbindungsaufbau / Initialisierung |
| Langsames Blinken (1 Hz) | Config-Modus aktiv |
| Dauerlicht | Betriebsbereit, wartet auf Zahlung |
| Kurzes Ausschalten (300 ms) | Aktion gestartet – Relais/Servo ausgelöst |
| 200 ms an / 800 ms aus | NFC-Zahlung ausstehend (PENDING) |
| 2× kurzes Blinken | Zahlung erfolgreich |
| 3× kurzes Blinken | NFC-Timeout / Fehler |
| 1× Blinken (500 ms an/aus, 2 s Pause) | Fehlermuster 1: Kein WLAN |
| 2× Blinken (300 ms an/aus, 2 s Pause) | Fehlermuster 2: Kein Internet |
| 3× Blinken (250 ms an/aus, 2 s Pause) | Fehlermuster 3: Server nicht erreichbar |
| 4× Blinken (200 ms an/aus, 2 s Pause) | Fehlermuster 4: WebSocket-Verbindung fehlgeschlagen |

### Bedientaster

| Funktion | Taster |
|---|---|
| Config-Modus aufrufen | BOOT-Taster mind. 5 Sek. gedrückt halten |
| Neustart | Reset-Taster |

---

## Einrichtung und Inbetriebnahme

Die ZapBox wird nach der Fertigung getestet und mit der aktuellen Firmware ausgeliefert - sie ist aber nicht parametriert. Die Software wird aktiv weiterentwickelt, daher ist es empfehlenswert, die ZapBox gleich zu Beginn einmal mit der neuesten Firmware zu bespielen und dann eine Parametrierung durchzuführen. Dafür gibt es einen komfortablen [**Web-Installer Headless**](https://installer.zapbox.space/headless/).

### Schritt 1: Firmware-Update
1. Öffnet auf der rechten Seite das Panel, wie oben unter "Eingang - Micro-USB Buchse am Mikrocontroller" beschrieben.
2. Schließt die ZapBox an dem USB-C-Port mit einem Kabel an und verbindet es mit einem Computer.
3. Öffnet einen Chromium Browser, zum Beispiel Google Chrome, Microsoft Edge, Brave, Vivaldi, Opera oder [Helium](https://helium.computer/).

### Schritt 2: Parametrierung
1. Navigiert im Browser zur Web-Installer-Seite.
2. Folgt den Anweisungen auf der Seite, um die gewünschten Parameter wie `WiFi SSID`, `WiFi Passwort` und `Device Settings String` einzugeben.
3. Speichert die Einstellungen und startet die ZapBox neu.

> **Hinweis:** Während der Einrichtung sollte keine Last an den Ausgängen angeschlossen sein, um Fehlfunktionen oder Schäden am Mikrocontroller zu vermeiden.

Die ZapBox wird nach der Initialisierung den QR-Code des Produkts anzeigen und ist bereit für die erste Zahlung und anschließende Schaltaktion.

---

## Technische Daten

| Eigenschaft | Wert |
|---|---|
| Versorgungsspannung | 5 V DC über USB-C |
| Maximaler Eingangsstrom | 5,0 A |
| Ausgangsleistung | max. 3,0 A (empfohlen) |
| Mikrocontroller | ESP32 Dev Module (WROOM-32) |
| Display | keines (Headless) |
| Statusanzeige | Status-LED / Action-LED |
| Temperaturbereich | 0–40 °C |
| Kommunikation | Wi-Fi (ESP32) |
| Zahlungsprotokoll | Bitcoin Lightning Network |

---

## Sicherheitshinweise

- Betreiben Sie das Gerät ausschließlich mit der angegebenen Versorgungsspannung.
- Überschreiten Sie nicht die maximalen Strombelastungen der Ausgänge.
- Führen Sie keine Arbeiten an den Relaiskontakten unter Last durch.
- Das Gerät ist nicht für den Einsatz in feuchten oder nassen Umgebungen geeignet.
- Sorgen Sie für ausreichende Belüftung um das Gerät.
- Außerhalb der Reichweite von Kindern aufbewahren.

---

## Weiterführende Links

| Ressource | Link |
|---|---|
| Übersicht aller ZapBox-Modelle | https://zapbox.space/ |
| Web-Installer, Kurzübersicht & Fehlerbehebung | https://installer.zapbox.space/ |
| Detaillierte Dokumentation (Parameter & Funktionen) | https://ereignishorizont.xyz/zapbox/ |
| GitHub-Repository (Software, E-Layouts, 3D-Druckdateien, Bedienungsanleitungen, etc.) | https://github.com/AxelHamburch/ZapBox |
| ZapBox Extension | https://github.com/AxelHamburch/zapbox_extension |
| LNbits | https://lnbits.com/ |

---

*Änderungen und Irrtümer vorbehalten. Stand: 2026*

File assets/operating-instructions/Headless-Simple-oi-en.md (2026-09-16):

# ZapBox Headless Simple – Operating Instructions

**Language:** English | **Version:** oi967253
---
## Table of Contents

1. [Overview](#overview)
2. [Views](#views)
3. [Connections](#connections)
4. [Controls](#controls)
5. [Setup and Commissioning](#setup-and-commissioning)
6. [Technical Data](#technical-data)
7. [Safety Instructions](#safety-instructions)
8. [Further Links](#further-links)

---

## Overview

The **ZapBox Headless Simple** is an electronic switch for Bitcoin Lightning payments without a display. A payment via the Lightning Network can be used to switch an output – ideal for embedded applications, concealed installations, machine building, and anywhere a display is not needed.

The operating state is indicated exclusively via a **status LED**. A second **action LED** indicates the switching function.

### Basic Equipment

| Component | Description |
|---|---|
| Microcontroller | ESP32 Dev Module (no display) |
| Input | Dual USB-A and USB-C |
| Output | Dual USB-A and USB-C |
| Status display | Status LED with blink patterns and action LED as feedback |
| Control | Micro switch for BOOT (config mode) and reset |

## Views

Three-side view

*Figure 1: Three-side view*

---

## Connections

### Input - Dual USB-A and USB-C socket for power supply (5V)

Power the device via the **Power IN** connector using a USB-C cable with **5 V DC (max. 5 A)**.

> **Note:** The USB power connector does not support automatic USB-C power negotiation (no USB-C Power Delivery). Some USB-C chargers or power modules therefore do not recognize the ZapBox as a load and will not supply power. In this case, use a **USB-A output** of the power supply or an alternative 5 V power source. The maximum current must not exceed 3 A.

### Input - Micro-USB socket on the microcontroller (data access, on the side)

To read or transfer data from the device, connect the ZapBox to a computer or laptop:

1. On the **right side**, next to the USB connectors, there is a small panel. Open the panel with a **narrow screwdriver** by carefully prying it out.
2. Connect a Micro-USB cable to the microcontroller.

Micro USB Port

*Figure 2: Micro USB Port*

> **Important note:** The USB connector directly on the microcontroller is intended exclusively for flashing the firmware and transferring configuration parameters. During the flashing process, no load may be connected or switched at the output, as this can lead to malfunctions or **damage to the microcontroller**.
>
> It is therefore recommended to either:
> - not connect any load at the output while the USB connection is active, or
> - additionally connect the regular **Power-IN input** to the same power supply. This ensures that the current for the power relay does not flow through the microcontroller and overload it.

### Output - Dual USB-A and USB-C socket (switched 5V voltage)

The USB sockets are switched via a relay contact. The **total load** of the sockets should **not exceed 3 A**.

---

## Controls

The ZapBox Headless has **no display**. The operating state is signaled exclusively via the **status LED** (GPIO 21 (external) / GPIO 2 (onboard)) and **action LED** (GPIO 13).

### Status LED – Blink Patterns

| Pattern | Meaning |
|---|---|
| 3× short blink on start | Boot complete |
| Fast blinking | Connecting / initializing |
| Slow blinking (1 Hz) | Config mode active |
| Steady light | Ready for operation, waiting for payment |
| Short off (300 ms) | Action started – relay/servo triggered |
| 200 ms on / 800 ms off | NFC payment pending (PENDING) |
| 2× short blink | Payment successful |
| 3× short blink | NFC timeout / error |
| 1× blink (500 ms on/off, 2 s pause) | Error pattern 1: No WiFi |
| 2× blink (300 ms on/off, 2 s pause) | Error pattern 2: No internet |
| 3× blink (250 ms on/off, 2 s pause) | Error pattern 3: Server unreachable |
| 4× blink (200 ms on/off, 2 s pause) | Error pattern 4: WebSocket connection failed |

### Control Buttons

| Function | Button |
|---|---|
| Open config mode | Hold BOOT button for at least 5 sec. |
| Restart | Reset button |

---

## Setup and Commissioning

The ZapBox is tested after manufacturing and shipped with the current firmware - however, it is not yet parameterized. The software is under active development, so it is recommended to flash the ZapBox with the latest firmware right at the start and then perform the parameterization. A convenient [**Web Installer Headless**](https://installer.zapbox.space/headless/) is available for this.

### Step 1: Firmware Update
1. Open the panel on the right side, as described above under "Input - Micro-USB socket on the microcontroller".
2. Connect the ZapBox to the USB-C port with a cable and connect it to a computer.
3. Open a Chromium browser, for example Google Chrome, Microsoft Edge, Brave, Vivaldi, Opera, or [Helium](https://helium.computer/).

### Step 2: Parameterization
1. Navigate to the Web Installer page in the browser.
2. Follow the instructions on the page to enter the desired parameters such as `WiFi SSID`, `WiFi password`, and `Device Settings String`.
3. Save the settings and restart the ZapBox.

> **Note:** No load should be connected to the outputs during setup, to avoid malfunctions or damage to the microcontroller.

After initialization, the ZapBox will display the product's QR code and is ready for the first payment and subsequent switching action.

---

## Technical Data

| Property | Value |
|---|---|
| Supply voltage | 5 V DC via USB-C |
| Maximum input current | 5.0 A |
| Output power | max. 3.0 A (recommended) |
| Microcontroller | ESP32 Dev Module (WROOM-32) |
| Display | none (headless) |
| Status display | Status LED / action LED |
| Temperature range | 0–40 °C |
| Communication | Wi-Fi (ESP32) |
| Payment protocol | Bitcoin Lightning Network |

---

## Safety Instructions

- Operate the device only with the specified supply voltage.
- Do not exceed the maximum current load of the outputs.
- Do not perform any work on the relay contacts under load.
- The device is not suitable for use in damp or wet environments.
- Ensure adequate ventilation around the device.
- Keep out of the reach of children.

---

## Further Links

| Resource | Link |
|---|---|
| Overview of all ZapBox models | https://zapbox.space/ |
| Web Installer, quick overview & troubleshooting | https://installer.zapbox.space/ |
| Detailed documentation (parameters & functions) | https://ereignishorizont.xyz/zapbox/ |
| GitHub repository (software, PCB layouts, 3D print files, operating instructions, etc.) | https://github.com/AxelHamburch/ZapBox |
| ZapBox Extension | https://github.com/AxelHamburch/zapbox_extension |
| LNbits | https://lnbits.com/ |

---

*Subject to changes and errors. As of: 2026*

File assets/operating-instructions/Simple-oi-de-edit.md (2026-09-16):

# ZapBox Simple – Bedienungsanleitung

**Sprache:** Deutsch | **Version:** oi967281

---

## Inhaltsverzeichnis

1. [Übersicht](#übersicht)
2. [Ansichten](#ansichten)
3. [Anschlüsse](#anschlüsse)
4. [Bedienelemente](#bedienelemente)
5. [Einrichtung und Inbetriebnahme](#einrichtung-und-inbetriebnahme)
6. [Technische Daten](#technische-daten)
7. [Sicherheitshinweise](#sicherheitshinweise)
8. [Weiterführende Links](#weiterführende-links)

---

## Übersicht

Die **ZapBox Compact** ist ein elektronischer Schalter für Bitcoin-Lightning-Zahlungen. Mit einer Zahlung über das Lightning-Netzwerk lässt sich ein Ausgang schalten – ideal für Automaten, Präsentationen, Eventsteuerung und viele weitere Anwendungen.

### Grundausstattung

| Komponente | Beschreibung |
|---|---|
| Mikrocontroller | T-Display-S3 mit 1,9" LCD-Display |
| Frontpanel | 35° Display |
| Eingang | Dual USB-A und USB-C |
| Ausgang | Dual USB-A und USB-C |
| Bedienelement | Zwei On-board-Mikrotaster |
| Option BTC-Ticker | Aktivierbar über den Web Installer |

---

## Ansichten

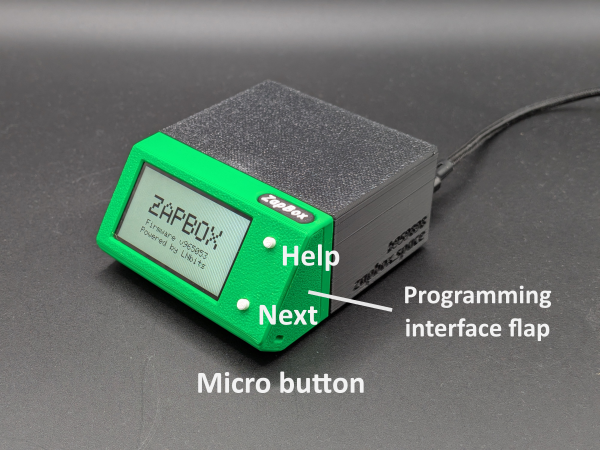
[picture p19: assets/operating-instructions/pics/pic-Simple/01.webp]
Frontansicht


*Bild 1: Frontansicht*

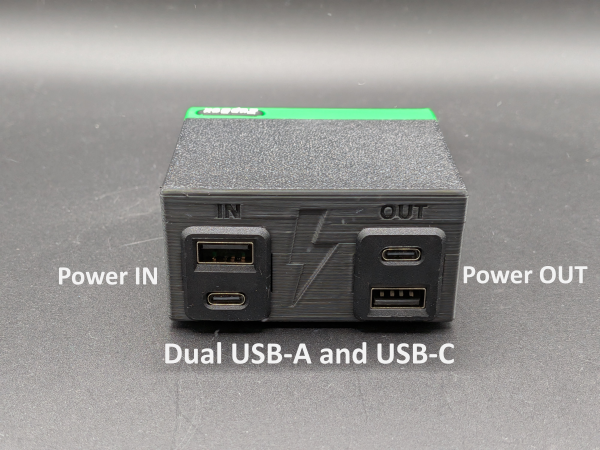
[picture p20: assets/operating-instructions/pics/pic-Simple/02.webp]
Rückansicht


*Bild 2: Rückansicht*

---

## Anschlüsse

### Eingang - Dual USB-A und USB-C Buchse zur Spannungsversorgung (5V)

Versorgen Sie das Gerät über den Anschluss **Power IN** mit einem USB-C/A-Kabel mit **5 V DC (max. 5 A)**.

> **Hinweis:** Der USB-Power-Anschluss unterstützt keine automatische USB-C-Leistungsanforderung (kein USB-C Power Delivery). Einige USB-C-Ladegeräte oder Powermodule erkennen die ZapBox daher nicht als Verbraucher und liefern keinen Strom. Verwenden Sie in diesem Fall einen **USB-A-Ausgang** der Spannungsversorgung oder eine alternative 5-V-Stromquelle. Die maximale Stromstärke darf 3 A nicht überschreiten.

---

### Eingang - USB-C Buchse am Mikrocontroller (Datenzugang, hinter rechtem Seitenpanel)

Um Daten vom Gerät zu lesen oder zu übertragen, verbinden Sie die ZapBox mit einem Computer oder Laptop:

1. An der **rechten Seite der Frontblende** befindet sich eine kleine, verdeckte Klappe.
2. Öffnen Sie die Klappe, indem Sie von unten mit einem **schmalen Schraubendreher** die Klappe nach rechts wegschieben.
3. Schließen Sie ein USB-C-Kabel am darunter liegenden Anschluss des Mikrocontrollers an.

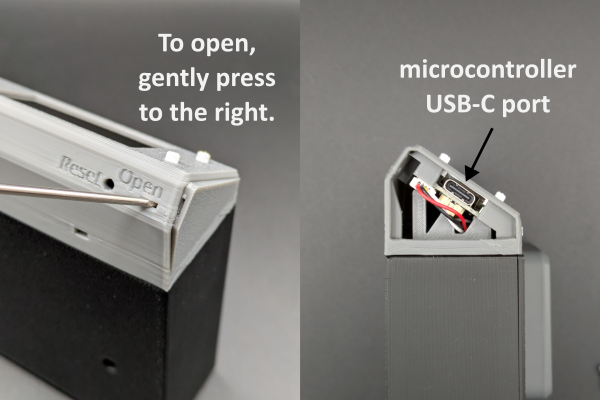
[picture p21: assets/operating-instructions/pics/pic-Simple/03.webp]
Panel öffnen und USB-C-Anschluss


*Bild: Panel öffnen und USB-C-Anschluss für Daten*

> **Wichtiger Hinweis:** Der USB-Anschluss direkt am Mikrocontroller ist ausschließlich zum Flashen der Firmware und zur Übertragung von Konfigurationsparametern vorgesehen. Während des Flashvorgangs darf keine Last am Ausgang angeschlossen oder geschaltet werden, da dies zu Fehlfunktionen oder zur **Beschädigung des Mikrocontrollers** führen kann.
>
> Es wird daher empfohlen:
> - während der USB-Verbindung keine Last am Ausgang anzuschließen oder
> - den regulären **Power-IN-Eingang** zusätzlich an dieselbe Spannungsversorgung anzuschließen. Dadurch wird sichergestellt, dass der Strom für das Leistungsrelais nicht über den Mikrocontroller fließt und diesen überlastet.

---

### Fehlerdiagnose und -behebung 

Die ZapBox verfügt über eine komfortable Fehleranzeige über das Display. Es gibt vier grundlegende Fehler, die priorisiert sind:

| Prio. | Fehlerart | Abkürzung | Erkennungsmethode | Beschreibung |
|---|---|---|---|---|
| 1 | **NO WIFI** | NW | WiFi-Verbindungsstatus | WiFi-Netzwerk nicht verbunden<br>-> Sind die WiFi-Daten korrekt?<br>-> Ist das WiFi-Signal zu schwach? |
| 2 | **NO INTERNET** | NI | HTTP-Check zu Google | Internetverbindung verloren<br>-> Ist das Internet erreichbar? |
| 3 | **NO SERVER** | NS | TCP-Port 443-Check | LNbits-Server nicht erreichbar<br>-> Ist die Server-Hardware ausgefallen?<br>-> Ist der Geräte-String korrekt? |
| 4 | **NO WEBSOCKET** | NWS | WebSocket-Verbindungsstatus | WebSocket-Protokoll-/Handshake-Fehler<br>-> Ist LNbits ausgefallen?<br>-> Ist der Geräte-String korrekt? |

Die Fehlermeldungen werden auch geloggt und können über den *Report Mode* abgerufen werden:

- Drücken Sie die HELP-Taste zweimal schnell hintereinander, um Fehlerzähler (0-99) für alle vier Fehlertypen mit ihren Auftretenshäufigkeiten anzuzeigen.
- Drücken Sie die LED-Taste dreimal schnell hintereinander (falls eine externe LED-Taste verfügbar ist).

Weitere aktuelle Informationen zu Fehlerbeschreibungen können auf der Web-Installer-Seite in den Kapiteln "Error Detection & Report" und "Troubleshoot" nachgelesen werden. 

---

### Ausgang - Dual USB-A und USB-C (geschaltete 5V Spannung)

Die USB-Buchse wird über einen Relais-Schaltkontakt geschaltet. Die **Gesamtbelastung** der Buchsen sollte **3 A nicht überschreiten**.

---

## Bedienelemente

Die ZapBox verfügt über zwei kleine **On-board-Mikrotaster**, die direkt mit dem Mikrocontroller verbunden sind. Alle Funktionen sind über die Mikrotaster erreichbar. Zusätzlich hat die ZapBox an der Unterseite des Frontpanels einen Reset Taster und an der Seite zwei Schiebeschalter.

### Funktionsübersicht - Mikrotaster

| Funktion | Mikrotaster |
|---|---|
| Hilfe-Seite anzeigen | 1× HELP drücken | 
| Nächste Seite / Produktwechsel | 1× NEXT drücken |
| REPORT-Seite anzeigen | 2× HELP drücken | 
| Config-Modus aufrufen | NEXT mind. 5 Sek. gedrückt halten |

---

## Einrichtung und Inbetriebnahme

Die ZapBox wird nach der Fertigung getestet und mit der aktuellen Firmware ausgeliefert - sie ist aber nicht parametriert. Die Software wird aktiv weiterentwickelt, daher ist es empfehlenswert, die ZapBox gleich zu Beginn einmal mit der neuesten Firmware zu bespielen und dann eine Parametrierung durchzuführen. Dafür gibt es einen komfortablen [**Web-Installer**](https://installer.zapbox.space/).

### Schritt 1: Firmware-Update
1. Öffnet das rechte Seitenpanel der Frontblende, wie oben unter "Eingang - USB-C Buchse am Mikrocontroller" beschrieben.
2. Schließt die ZapBox an dem USB-C-Port mit einem Kabel an und verbindet es mit einem Computer.
3. Öffnet einen Chromium Browser, zum Beispiel Google Chrome, Microsoft Edge, Brave, Vivaldi, Opera oder [Helium](https://helium.computer/).

### Schritt 2: Parametrierung
1. Navigiert im Browser zur Web-Installer-Seite.
2. Folgt den Anweisungen auf der Seite, um die gewünschten Parameter wie `WiFi SSID`, `WiFi Passwort` und `Device Settings String` einzugeben.
3. Speichert die Einstellungen und startet die ZapBox neu.

> **Hinweis:** Während der Einrichtung sollte keine Last an den Ausgängen angeschlossen sein, um Fehlfunktionen oder Schäden am Mikrocontroller zu vermeiden.

Die ZapBox wird nach der Initialisierung den QR-Code des Produkts anzeigen und ist bereit für die erste Zahlung und anschließende Schaltaktion. 

---

## Technische Daten

| Eigenschaft | Wert |
|---|---|
| Versorgungsspannung | 5 V DC über USB-C |
| Maximaler Eingangsstrom | 5,0 A |
| Ausgangsleistung | max. 3,0 A (empfohlen) |
| Display | 1,9" LCD (T-Display-S3) |
| Temperaturbereich | 0–40 °C |
| Kommunikation | Wi-Fi (ESP32-S3) |
| Zahlungsprotokoll | Bitcoin Lightning Network |

---

## Sicherheitshinweise

- Betreiben Sie das Gerät ausschließlich mit der angegebenen Versorgungsspannung.
- Überschreiten Sie nicht die maximalen Strombelastungen der Ausgänge.
- Führen Sie keine Arbeiten an den Relaiskontakten unter Last durch.
- Das Gerät ist nicht für den Einsatz in feuchten oder nassen Umgebungen geeignet.
- Sorgen Sie für ausreichende Belüftung um das Gerät. 
- Außerhalb der Reichweite von Kindern aufbewahren.

---

## Weiterführende Links

| Ressource | Link |
|---|---|
| Übersicht aller ZapBox-Modelle | https://zapbox.space/ |
| Web-Installer, Kurzübersicht & Fehlerbehebung | https://installer.zapbox.space/ |
| Detaillierte Dokumentation (Parameter & Funktionen) | https://ereignishorizont.xyz/zapbox/ |
| GitHub-Repository (Software, E-Layouts, 3D-Druckdateien, Bedienungsanleitungen, etc.) | https://github.com/AxelHamburch/ZapBox |
| ZapBox Extension | https://github.com/AxelHamburch/zapbox_extension |
| LNbits | https://lnbits.com/ |

---

*Änderungen und Irrtümer vorbehalten. Stand: 2026*

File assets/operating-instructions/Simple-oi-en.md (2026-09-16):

# ZapBox Simple – Operating Instructions

**Language:** English | **Version:** oi967281

---

## Table of Contents

1. [Overview](#overview)
2. [Views](#views)
3. [Connections](#connections)
4. [Controls](#controls)
5. [Setup and Commissioning](#setup-and-commissioning)
6. [Technical Data](#technical-data)
7. [Safety Instructions](#safety-instructions)
8. [Further Links](#further-links)

---

## Overview

The **ZapBox Compact** is an electronic switch for Bitcoin Lightning payments. A payment via the Lightning Network can be used to switch an output – ideal for vending machines, presentations, event control, and many other applications.

### Basic Equipment

| Component | Description |
|---|---|
| Microcontroller | T-Display-S3 with 1.9" LCD display |
| Front panel | 35° display |
| Input | Dual USB-A and USB-C |
| Output | Dual USB-A and USB-C |
| Control | Two on-board micro switches |
| Option BTC ticker | Activatable via the Web Installer |

---

## Views

Front view

*Figure 1: Front view*

Rear view

*Figure 2: Rear view*

---

## Connections

### Input - Dual USB-A and USB-C socket for power supply (5V)

Power the device via the **Power IN** connector using a USB-C/A cable with **5 V DC (max. 5 A)**.

> **Note:** The USB power connector does not support automatic USB-C power negotiation (no USB-C Power Delivery). Some USB-C chargers or power modules therefore do not recognize the ZapBox as a load and will not supply power. In this case, use a **USB-A output** of the power supply or an alternative 5 V power source. The maximum current must not exceed 3 A.

---

### Input - USB-C socket on the microcontroller (data access, behind the right side panel)

To read or transfer data from the device, connect the ZapBox to a computer or laptop:

1. On the **right side of the front panel** there is a small, concealed flap.
2. Open the flap by pushing it to the right from below using a **narrow screwdriver**.
3. Connect a USB-C cable to the microcontroller's connector underneath.

Opening the panel and USB-C connector

*Figure: Opening the panel and USB-C connector for data*

> **Important note:** The USB connector directly on the microcontroller is intended exclusively for flashing the firmware and transferring configuration parameters. During the flashing process, no load may be connected or switched at the output, as this can lead to malfunctions or **damage to the microcontroller**.
>
> It is therefore recommended to either:
> - not connect any load at the output while the USB connection is active, or
> - additionally connect the regular **Power-IN input** to the same power supply. This ensures that the current for the power relay does not flow through the microcontroller and overload it.

---

### Error Diagnosis and Troubleshooting

The ZapBox has a convenient error display via the screen. There are four basic errors, which are prioritized:

| Prio. | Error type | Abbreviation | Detection method | Description |
|---|---|---|---|---|
| 1 | **NO WIFI** | NW | WiFi connection status | WiFi network not connected<br>-> Is the WiFi data correct?<br>-> Is the WiFi signal too weak? |
| 2 | **NO INTERNET** | NI | HTTP check to Google | Internet connection lost<br>-> Is the internet reachable? |
| 3 | **NO SERVER** | NS | TCP port 443 check | LNbits server unreachable<br>-> Has the server hardware failed?<br>-> Is the device string correct? |
| 4 | **NO WEBSOCKET** | NWS | WebSocket connection status | WebSocket protocol/handshake error<br>-> Has LNbits failed?<br>-> Is the device string correct? |

The error messages are also logged and can be retrieved via the *Report Mode*:

- Press the HELP button twice quickly in succession to show error counters (0-99) for all four error types with their occurrence frequencies.
- Press the LED button three times quickly in succession (if an external LED button is available).

Further up-to-date information on error descriptions can be found on the Web Installer page in the "Error Detection & Report" and "Troubleshoot" chapters.

---

### Output - Dual USB-A and USB-C (switched 5V voltage)

The USB sockets are switched via a relay contact. The **total load** of the sockets should **not exceed 3 A**.

---

## Controls

The ZapBox has two small **on-board micro switches** that are connected directly to the microcontroller. All functions can be accessed via the micro switches. In addition, the ZapBox has a reset button on the underside of the front panel and two slide switches on the side.

### Function Overview - Micro Switches

| Function | Micro switch |
|---|---|
| Show help page | Press HELP once |
| Next page / product change | Press NEXT once |
| Show REPORT page | Press HELP twice |
| Open config mode | Hold NEXT for at least 5 sec. |

---

## Setup and Commissioning

The ZapBox is tested after manufacturing and shipped with the current firmware - however, it is not yet parameterized. The software is under active development, so it is recommended to flash the ZapBox with the latest firmware right at the start and then perform the parameterization. A convenient [**Web Installer**](https://installer.zapbox.space/) is available for this.

### Step 1: Firmware Update
1. Open the right side panel of the front panel, as described above under "Input - USB-C socket on the microcontroller".
2. Connect the ZapBox to the USB-C port with a cable and connect it to a computer.
3. Open a Chromium browser, for example Google Chrome, Microsoft Edge, Brave, Vivaldi, Opera, or [Helium](https://helium.computer/).

### Step 2: Parameterization
1. Navigate to the Web Installer page in the browser.
2. Follow the instructions on the page to enter the desired parameters such as `WiFi SSID`, `WiFi password`, and `Device Settings String`.
3. Save the settings and restart the ZapBox.

> **Note:** No load should be connected to the outputs during setup, to avoid malfunctions or damage to the microcontroller.

After initialization, the ZapBox will display the product's QR code and is ready for the first payment and subsequent switching action.

---

## Technical Data

| Property | Value |
|---|---|
| Supply voltage | 5 V DC via USB-C |
| Maximum input current | 5.0 A |
| Output power | max. 3.0 A (recommended) |
| Display | 1.9" LCD (T-Display-S3) |
| Temperature range | 0–40 °C |
| Communication | Wi-Fi (ESP32-S3) |
| Payment protocol | Bitcoin Lightning Network |

---

## Safety Instructions

- Operate the device only with the specified supply voltage.
- Do not exceed the maximum current load of the outputs.
- Do not perform any work on the relay contacts under load.
- The device is not suitable for use in damp or wet environments.
- Ensure adequate ventilation around the device.
- Keep out of the reach of children.

---

## Further Links

| Resource | Link |
|---|---|
| Overview of all ZapBox models | https://zapbox.space/ |
| Web Installer, quick overview & troubleshooting | https://installer.zapbox.space/ |
| Detailed documentation (parameters & functions) | https://ereignishorizont.xyz/zapbox/ |
| GitHub repository (software, PCB layouts, 3D print files, operating instructions, etc.) | https://github.com/AxelHamburch/ZapBox |
| ZapBox Extension | https://github.com/AxelHamburch/zapbox_extension |
| LNbits | https://lnbits.com/ |

---

*Subject to changes and errors. As of: 2026*

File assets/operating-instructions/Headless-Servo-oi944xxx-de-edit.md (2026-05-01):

# ZapBox Headless Servo – Bedienungsanleitung

**Sprache:** Deutsch | **Version:** oi944935

---

## Inhaltsverzeichnis

1. [Einleitung](#einleitung)
2. [Ansichten](#ansichten)
3. [Anschlüsse](#anschlüsse)
4. [Bedienelemente](#bedienelemente)
5. [Einrichtung und Inbetriebnahme](#einrichtung-und-inbetriebnahme)
6. [Parametrierung](#parametrierung)
7. [NFC-Modul (Option)](#nfc-modul-option)
8. [Technische Daten](#technische-daten)
9. [Sicherheitshinweise](#sicherheitshinweise)
10. [Weiterführende Links](#weiterführende-links)

---

## Einleitung

Die **ZapBox Headless Servo** ist ein elektronischer Schalter für Bitcoin-Lightning-Zahlungen ohne Display. Mit einer Zahlung über das Lightning-Netzwerk lässt sich ein Ausgang schalten – ideal für eingebettete Anwendungen, verdeckte Installationen, Maschinenbau und überall dort, wo kein Display benötigt wird.

Die ZapBox Headless Servo verfügt über einen Steckverbinder zum Anschluss externer Relais mit 5-V-Ansteuerung sowie digitaler Servomotoren. Unterstützt werden sowohl 180°-Servomotoren für Positionierungsaufgaben als auch 360°-Servomotoren für kontinuierliche Rotationsanwendungen.
Zusätzlich stehen auf der Steckverbindung zwei universelle Anschlüsse für Aktoren und Sensoren zur Verfügung. Die Konfiguration und Parametrierung erfolgt über den Web Installer.

Der Betriebszustand wird ausschließlich über eine **Status-LED** angezeigt. Eine zweite **Action-LED** zeigt die Schaltfunktion an.

### Grundausstattung

| Komponente | Beschreibung |
|---|---|
| Mikrocontroller | ESP32 Dev Module (kein Display) |
| Eingang | USB-C (Power IN) |
| Ausgang | 5-polige Steckverbinder (15EDG 3,5 mm) |
| Statusanzeige | Status-LED mit Blinkmustern und Action-LED als Rückmeldung |
| Bedienelement | Mikrotaster für BOOT (Config-Modus) und Reset |
| Option NFC-Modul | Für Bolt Cards (NTAG424 DNA) und Standard NTAG213/215/216 (mit LNURL-withdraw) |

---

## Ansichten

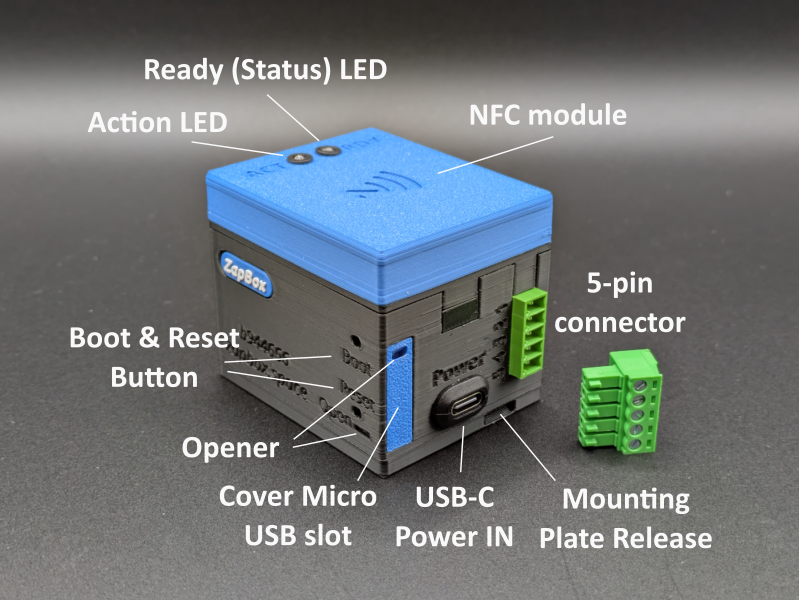
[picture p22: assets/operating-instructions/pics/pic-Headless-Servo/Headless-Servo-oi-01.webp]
Frontansicht-Draufsicht


*Bild 1: Frontansicht / Draufsicht*

---

## Anschlüsse

### Eingang - USB-C Buchse zur Spannungsversorgung (5V)

Versorgen Sie das Gerät über den Anschluss **Power IN** mit einem USB-C-Kabel mit **5 V DC (max. 5 A)**.

> **Hinweis:** Der USB-Power-Anschluss unterstützt keine automatische USB-C-Leistungsanforderung (kein USB-C Power Delivery). Einige USB-C-Ladegeräte oder Powermodule erkennen die ZapBox daher nicht als Verbraucher und liefern keinen Strom. Verwenden Sie in diesem Fall einen **USB-A-Ausgang** der Spannungsversorgung oder eine alternative 5-V-Stromquelle. Die maximale Stromstärke darf 3 A nicht überschreiten.

---

### Eingang - Micro-USB Buchse am Mikrocontroller (Datenzugang, vorne)

Um Daten vom Gerät zu lesen oder zu übertragen, verbinden Sie die ZapBox mit einem Computer oder Laptop:

1. An der **Vorderseite links** befindet sich eine kleines Panel links neben den USB-Anschlüssen. Öffnen Sie das Panel, indem Sie von unten mit einem **schmalen Schraubendreher** das Panel nach rechts wegschieben.
2. Schließen Sie ein Micro-USB-Kabel an den Mikrocontroller an.

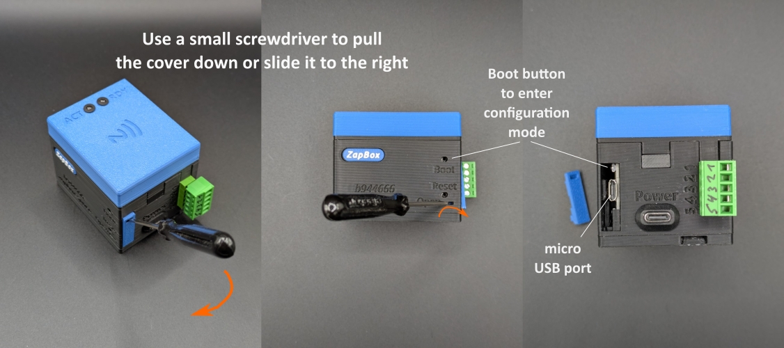
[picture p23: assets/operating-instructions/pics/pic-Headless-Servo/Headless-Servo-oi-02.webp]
Panel öffnen für Datenverbindung mit Micro USB-Port


*Bild 2: Panel öffnen für Datenverbindung mit Micro USB-Port*

> **Wichtiger Hinweis:** Der USB-Anschluss direkt am Mikrocontroller ist ausschließlich zum Flashen der Firmware und zur Übertragung von Konfigurationsparametern vorgesehen. Während des Flashvorgangs darf keine Last am Ausgang angeschlossen oder geschaltet werden, da dies zu Fehlfunktionen oder zur **Beschädigung des Mikrocontrollers** führen kann.
>
> Es wird daher empfohlen:
> - während der USB-Verbindung keine Last am Ausgang anzuschließen oder
> - den regulären **Power-IN-Eingang** zusätzlich an dieselbe Spannungsversorgung anzuschließen. Dadurch wird sichergestellt, dass der Strom für das Leistungsrelais nicht über den Mikrocontroller fließt und diesen überlastet.

---

### Ausgang - 5-poliger Steckverbinder

**Klemmenbelegung:**
| Klemme | Funktion | Anschlussoption | Verwendung |
|---|---|---|---|
| 1 | 5V | Ausgang (Eingang möglich) | Spannungsversorgung für den Servo, etc. |
| 2 | GND | Ausgang (Eingang möglich) | Masseanschluss für den Servo, etc. |
| 3 | Relais oder Servomotor | Output | 3,3V Servo- bzw. Relaissteuersignal |
| 4 | Sensor / Aktor 1 | Eingang oder Ausgang | Sensor oder Aktor 1 |
| 5 | Sensor / Aktor 2 | Eingang oder Ausgang | Sensor oder Aktor 2 |

Die ZapBox kann entweder über den USB-C-Anschluss mit einer 5-V-Versorgungsspannung oder über die Klemmen 1 und 2 betrieben werden.
Für die Klemmen 3 bis 5 stehen optionale Funktionen zur Verfügung, die über den Web Installer eingestellt und parametriert werden müssen. Weitere Informationen hierzu finden sich unter „Optional Settings and Functions – ZapBox Mode“ bzw. „Special Features for Vending Machines“ im Web Installer.
Standardmäßig ist der Ausgang für Klemme 3 auf „Relay“ eingestellt, während die Klemmen 4 und 5 auf „No function“ gesetzt sind.

---

## Bedienelemente

Die ZapBox Headless hat **kein Display**. Der Betriebszustand wird ausschließlich über die **Status-LED** (GPIO 21 (extern) / GPIO 2 (onboard)) und **Action-LED** (GPIO 13) signalisiert.

### Status-LED – Blinkmuster

| Muster | Bedeutung |
|---|---|
| 3× kurzes Blinken beim Start | Boot abgeschlossen |
| Schnelles Blinken | Verbindungsaufbau / Initialisierung |
| Langsames Blinken (1 Hz) | Config-Modus aktiv |
| Dauerlicht | Betriebsbereit, wartet auf Zahlung |
| Kurzes Ausschalten (300 ms) | Aktion gestartet – Relais/Servo ausgelöst |
| 200 ms an / 800 ms aus | NFC-Zahlung ausstehend (PENDING) |
| 2× kurzes Blinken | Zahlung erfolgreich |
| 3× kurzes Blinken | NFC-Timeout / Fehler |
| Sehr schnelles Blinken (10 Hz) | Sensor "vending machine" angesprochen |
| 1× Blinken (500 ms an/aus, 2 s Pause) | Fehlermuster 1: Kein WLAN |
| 2× Blinken (300 ms an/aus, 2 s Pause) | Fehlermuster 2: Kein Internet |
| 3× Blinken (250 ms an/aus, 2 s Pause) | Fehlermuster 3: Server nicht erreichbar |
| 4× Blinken (200 ms an/aus, 2 s Pause) | Fehlermuster 4: WebSocket-Verbindung fehlgeschlagen |
| Aus | Keine Spannungsversorgung |

### Bedientaster

| Funktion | Taster |
|---|---|
| Config-Modus aufrufen | BOOT-Taster mind. 5 Sek. gedrückt halten |
| Neustart | Reset-Taster |

### Montagehalterung mit Schnapp-Arretierung

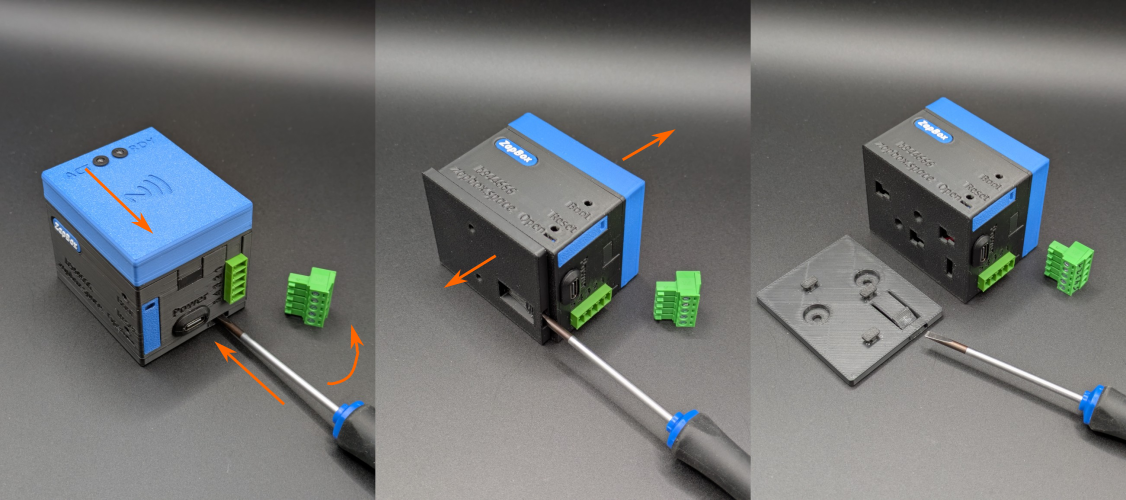
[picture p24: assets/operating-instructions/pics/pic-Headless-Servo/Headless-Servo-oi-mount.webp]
Lösen einer Montagehalter einer Headless mit NFC-Modul


*Bild 3: Lösen der Montagehalterung einer Headless mit NFC-Modul*

> **Hinweis:** Die ZapBox ist auf der Montagehalterung nur aufgeschoben und mit einem Schnappverschluss arretiert. Die Arretierung kann mit einem flachen Schraubendreher gelöst werden. Dazu den Schraubendreher vorsichtig in den Schlitz einschieben, leicht anheben und dabei den oberen Teil der ZapBox in Richtung des Schraubendrehers drücken. Die Verbindung sollte sich lösen und die ZapBox kann von der Montageplatte durch anheben getrennt werden.

---

## Einrichtung und Inbetriebnahme

Die ZapBox wird nach der Fertigung getestet und mit der aktuellen Firmware ausgeliefert - sie ist aber nicht parametriert. Die Software wird aktiv weiterentwickelt, daher ist es empfehlenswert, die ZapBox gleich zu Beginn einmal mit der neuesten Firmware zu bespielen und dann eine Parametrierung durchzuführen. Dafür gibt es einen komfortablen [**Web-Installer**](https://installer.zapbox.space/).

### Schritt 1: Firmware-Update
1. Öffnet das rechte Seitenpanel der Frontblende, wie oben unter "Seitenpanel öffnen" beschrieben.
2. Schließt die ZapBox an dem USB-C-Port mit einem Kabel an und verbindet es mit einem Computer.
3. Öffnet einen Chromium Browser, zum Beispiel Google Chrome, Microsoft Edge, Brave, Vivaldi, Opera oder [Helium](https://helium.computer/).

### Schritt 2: Parametrierung
1. Navigiert im Browser zur Web-Installer-Seite.
2. Folgt den Anweisungen auf der Seite, um die gewünschten Parameter wie `WiFi SSID`, `WiFi Passwort` und `Device Settings String` einzugeben.
3. Speichert die Einstellungen und startet die ZapBox neu.

> **Hinweis:** Während der Einrichtung sollte keine Last an den Ausgängen angeschlossen sein, um Fehlfunktionen oder Schäden am Mikrocontroller zu vermeiden.

Nach der Initialisierung leuchtet die Status-LED dauerhaft – die ZapBox ist betriebsbereit und wartet auf die erste Zahlung.

### Fehlerdiagnose und -behebung 

Die ZapBox zeigt Fehler über einen LED-Fehlerblinkcode an. Siehe dazu den vorherigen Kapitel *Status-LED – Blinkmuster*. Es gibt vier grundlegende Fehler, die priorisiert sind:

| Prio. | Fehlerart | Abkürzung | Erkennungsmethode | Beschreibung |
|---|---|---|---|---|
| 1 | **NO WIFI** | NW | WiFi-Verbindungsstatus | WiFi-Netzwerk nicht verbunden<br>-> Sind die WiFi-Daten korrekt?<br>-> Ist das WiFi-Signal zu schwach? |
| 2 | **NO INTERNET** | NI | HTTP-Check zu Google | Internetverbindung verloren<br>-> Ist das Internet erreichbar? |
| 3 | **NO SERVER** | NS | TCP-Port 443-Check | LNbits-Server nicht erreichbar<br>-> Ist die Server-Hardware ausgefallen?<br>-> Ist der Geräte-String korrekt? |
| 4 | **NO WEBSOCKET** | NWS | WebSocket-Verbindungsstatus | WebSocket-Protokoll-/Handshake-Fehler<br>-> Ist LNbits ausgefallen?<br>-> Ist der Geräte-String korrekt? |

Weitere aktuelle Informationen zu Fehlerbeschreibungen können auf der Web-Installer-Seite in den Kapiteln "Error Detection & Report" und "Troubleshoot" nachgelesen werden. 

---

## Parametrierung

Die ZapBox Headless Servo übernimmt nach der ersten Installation den Standardwert **"Relais"** für Klemme 3. Da die ZapBox kein intern verbautes Relais besitzt, können Sie ein externes **5 V-Relais (High-Level-Trigger)** ansteuern.

### Konfigurationsschritte

Grundvoraussetzung für die Parametrierung ist, dass der Web Installer mit dem ESP32 `✅ Connected` ist und die ZapBox sich im `✅ Config mode` befindet (wie unter **Einrichtung und Inbetriebnahme**, Punkt 5 beschrieben). Gehen Sie dann folgendermaßen vor:

1. **Konfiguration auslesen:** Klicken Sie auf `📖 Read Config`
2. **Parameter anpassen:** Ändern Sie die gewünschten Werte (siehe nachfolgende Abschnitte)
3. **Speichern und Neustart:** Klicken Sie `🔥 Write Config` und starten Sie mit `🔁 Restart` neu

### Servoansteuerung (Klemme 3)

Für Servomotoren müssen Sie im Web Installer unter **Optional settings and functions - ZapBox Mode** einen Servotyp auswählen:

- **180° Servo**
- **360° Servo** (kontinuierlich)

Nach Auswahl eines Servotyps erscheinen zusätzliche Parameterfelder für die Konfiguration.

### Universelle Eingänge/Ausgänge (GPIO)

Die ZapBox verfügt über zwei universell konfigurierbare **GPIOs** (General Purpose Input/Output):

| Klemme | Funktion | Beschreibung |
|---|---|---|
| 4 | Sensor / Aktor 1 | Eingang oder Ausgang, frei konfigurierbar |
| 5 | Sensor / Aktor 2 | Eingang oder Ausgang, frei konfigurierbar |

Weitere Informationen zur Konfiguration finden sich im Absatz **Special features for vending machines**.

> **Wichtig:** Alle Servomotoren sowie Sensoren/Aktoren **müssen mit 5 V betrieben werden**. Die ZapBox stellt 5 V an Klemme 1 zur Verfügung. 

---

## NFC-Modul (Option)

Je nach Ausstattung ist auf der **Oberseite der ZapBox** ein NFC-Modul verbaut. Alternativ ist das Modul auch separat erhältlich. Die ZapBox unterstützt aktuell folgende Kartentypen:

- **Boltcards** (NTAG424)
- **LNURL-Withdraw** von NTAG21x (213 / 215 / 216)

Voraussetzung für die Funktion ist die LNbits [ZapBox Extension](https://github.com/AxelHamburch/zapbox_extension). Sie muss von dem LNbits Server unterstützt werden. 

---

## Technische Daten

| Eigenschaft | Wert |
|---|---|
| Versorgungsspannung | 5 V DC über USB-C |
| Maximaler Eingangsstrom | 3,0 A |
| Ausgangsleistung | max. 3,0 A |
| Mikrocontroller | ESP32 Dev Module (WROOM-32) |
| Flash-Speicher | 4 MB |
| SRAM | 512 KB |
| Display | keines (Headless) |
| Statusanzeige | Status-LED / Action-LED |
| Temperaturbereich | 0–40 °C |
| Kommunikation | Wi-Fi (ESP32) |
| Ein-/Ausgänge | max. 3 - 1 Servo (oder Relais), 2 Sensoren/Aktoren |
| Zahlungsprotokoll | Bitcoin Lightning Network |

---

## Sicherheitshinweise

- Betreiben Sie das Gerät ausschließlich mit der angegebenen Versorgungsspannung.
- Bitte beachten Sie, dass Servomotoren hohe Ströme aufnehmen und die Stromversorgung überlasten können.
- Achten Sie darauf, den Servo oder einen Aktuator nicht zu aktivieren, wenn der ESP32 nur über den Micro-USB-Anschluss angeschlossen ist.
- Das Gerät ist nicht für den Einsatz in feuchten oder nassen Umgebungen geeignet.
- Außerhalb der Reichweite von Kindern aufbewahren.

---

## Weiterführende Links

| Ressource | Link |
|---|---|
| Übersicht aller ZapBox-Modelle | https://zapbox.space/ |
| Web-Installer, Kurzübersicht & Fehlerbehebung | https://installer.zapbox.space/headless/ |
| Detaillierte Dokumentation (Parameter & Funktionen) | https://ereignishorizont.xyz/zapbox/ |
| GitHub-Repository (Software, E-Layouts, 3D-Druckdateien, Bedienungsanleitungen) | https://github.com/AxelHamburch/ZapBox |
| ZapBox Extension | https://github.com/AxelHamburch/zapbox_extension |
| LNbits | https://lnbits.com/ |

---

*Änderungen und Irrtümer vorbehalten. Stand: 2026*

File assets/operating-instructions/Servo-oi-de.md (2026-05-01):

# ZapBox Servo – Bedienungsanleitung

**Sprache:** Deutsch | **Version:** oi947394

---

## Inhaltsverzeichnis

1. [Einleitung](#einleitung)
2. [Grundausstattung](#grundausstattung)
3. [Spannungsversorgung](#spannungsversorgung)
4. [16-poliger Steckverbinder](#16-poliger-steckverbinder)
5. [Schaltausgänge Kanal 1 bis 4](#schaltausgänge-kanal-1-bis-4)
6. [Schnittstelle Mikrocontroller (ESP32)](#schnittstelle-mikrocontroller-esp32)
7. [Bedienelemente](#bedienelemente)
8. [Montagehalterung mit Schnapp-Arretierung](#montagehalterung-mit-schnapp-arretierung)
9. [Einrichtung und Inbetriebnahme](#einrichtung-und-inbetriebnahme)
10. [NFC-Modul (Option)](#nfc-modul-option)
11. [Technische Daten](#technische-daten)
12. [Sicherheitshinweise](#sicherheitshinweise)
13. [Weiterführende Links](#weiterführende-links)

---

## Einleitung

Die **ZapBox Servo** ist ein elektronischer Schalter für Bitcoin-Lightning-Zahlungen. Mit einer Zahlung über das Lightning-Netzwerk lassen sich Ausgänge schalten – ideal für Automaten, Präsentationen, Eventsteuerung und viele weitere Anwendungen. 

Für umfängliche Automatisierungsaufgaben sind die Kontakte über einen 16-poligen abnehmbaren Steckverbinder nach außen geführt. Sie verfügt über einen zusätzlichen Sensoreingang, der individuell parametriert werden kann. Optional kann das NFC-Modul über die Steckerleiste extern geführt werden. 

Für einen vielseitigen Einsatz und einfachen Anschluss kann die Servo alternativ zum 5-V-USB-C-Anschluss auch über ein DC-Steckernetzteil betrieben werden. Sie verfügt über einen Weitbereichseingang (DC 6–36 V) mit einer Standard-DC-Buchse (5,5 × 2,1 mm).
Die benötigte 5-V-Spannung wird intern über einen selbstregelnden Spannungswandler erzeugt. Dadurch erweitern sich die Anwendungsmöglichkeiten erheblich, und die Spannungsversorgung der Ausgänge kann unabhängig von der 5-V-Versorgung intern bereitgestellt werden.

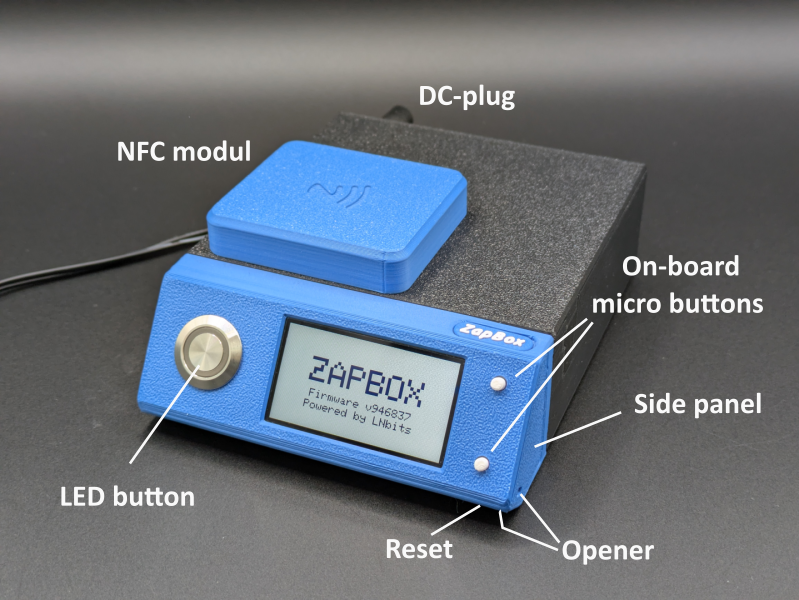
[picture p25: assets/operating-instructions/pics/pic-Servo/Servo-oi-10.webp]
Frontansicht


*Bild 1: Frontansicht und Rückansicht*

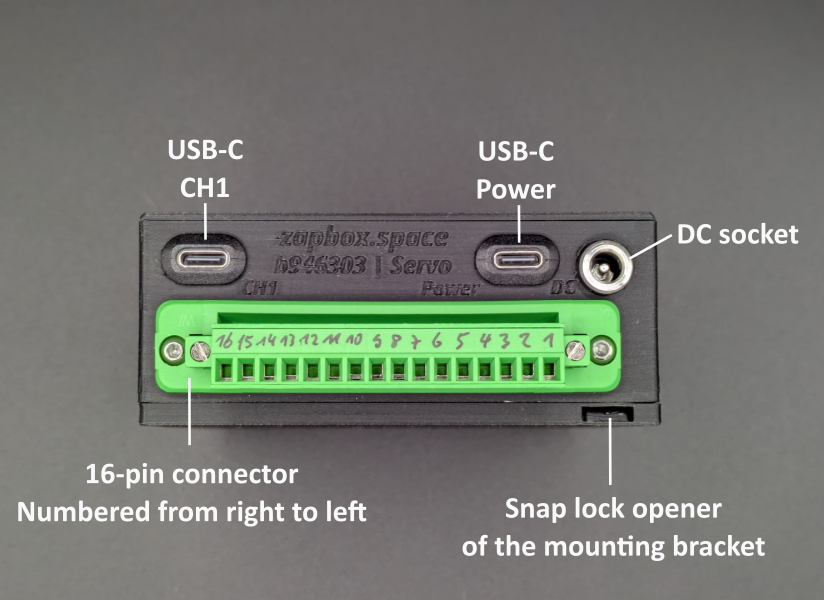
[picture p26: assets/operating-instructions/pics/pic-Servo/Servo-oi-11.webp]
Rückansicht


*Bild 1: Rückansicht*

## Grundausstattung

| Komponente | Beschreibung |
|---|---|
| Mikrocontroller | T-Display-S3 mit 1,9" LCD-Display |
| Frontpanel | Wahlweise mit 35° oder 90° Display Front (90° auch Einbau erhältlich) |
| Spannungsversorgung | USB-C (5V) und Weitbereichseingang DC 6V-36V (Hohlbuchse 5,5*2,1 mm) |
| Eingänge / Ausgänge | 16-polige Steckverbinder (15EDGWC 3,81mm) |
| Ausgänge | 2 Relaisausgänge CH1/CH4 - Schaltkontakte (NO/COM/NC) |
| Ausgänge | 2 Steuerausgänge CH2/CH3 - GPIO-Ausgänge zur Servosteuerung |
| Eingang | 1 Sensoreingang |
| Interface | Anschluss für externes NFC-Modul |
| Bedienelement | LED-Button (volle ZapBox-Funktionalität) |
| Option BTC-Ticker | Aktivierbar über den Web Installer |
| Option Boardtaster | Zwei On-board-Mikrotaster (optional verdeckt)|
| Option NFC-Modul | Für Bolt Cards (NTAG424 DNA) und Standard NTAG213/215/216 (mit LNURL-withdraw) |
| Option Schalter | Schiebeschalter (ON/OFF) |

---

## Spannungsversorgung

Die ZapBox Servo verfügt über einen USB-C-Anschluss sowie über eine DC-Hohlsteckerbuchse (5,5 × 2,1 mm) für gängige DC-Steckernetzteile.
Die Spannungsversorgung der Ausgänge kann individuell angepasst werden: entweder extern über die Klemmen 3 und 8 oder intern durch Abgriff der Speisespannung des Weitbereichseingangs.

### Spannungseingang USB-C Buchse (5V) 

Die ZapBox kann über den USB-C-Anschluss **Power** mit **5 V DC (max. 3 A)** versorgt werden. Die 5-V-Spannung wird über Klemme 1 des Steckverbinders nach außen geführt und kann dort zur Versorgung der Schaltausgänge auf die Klemmen 3 und 8 gebrückt werden.

> **Hinweis:** Der USB-Power-Anschluss unterstützt keine automatische USB-C-Leistungsanforderung (kein USB-C Power Delivery). Einige USB-C-Ladegeräte oder Powermodule erkennen die ZapBox daher nicht als Verbraucher und liefern keinen Strom. Verwenden Sie in diesem Fall einen **USB-A-Ausgang** der Spannungsversorgung oder eine alternative 5-V-Stromquelle. Die maximale Stromstärke darf 3 A nicht überschreiten.

### Spannungseingang DC-Hohlsteckerbuchse (6 V–36 V)

Die DC-Buchse ist als Weitbereichseingang für Spannungen von 6 V bis 36 V ausgelegt und eignet sich für gängige Netzteile mit z. B. 12 V oder 24 V Ausgangsspannung.
Die Eingangsspannung wird intern über einen Step-Down-Converter auf 5 V geregelt. Der Spannungswandler kann im Dauerbetrieb bis zu 1 A liefern. **Die Wärmeentwicklung ist dabei zu beachten ⚠️.**
Kurzzeitig sind auch Ströme bis 2 A möglich, in sehr kurzen Lastspitzen bis zu 2,5 A.

Intern besteht die Möglichkeit, die Eingangsspannung abzugreifen und auf die Steckerleiste zu verdrahten, um die Ausgangskanäle direkt mit der Eingangsspannung zu versorgen. Dies erfordert einen Eingriff in das Gerät und darf ausschließlich von elektrotechnischen Fachkräften durchgeführt werden. Details hierzu sind im [E-Layout](https://github.com/AxelHamburch/ZapBox#electrical-layout) der ZapBox Servo beschrieben.

> **Hinweis:** Der interne Spannungswandler besitzt eine begrenzte Leistungsfähigkeit. Bei hohen Lastströmen entsteht erhöhte Wärmeentwicklung, die zu einer Erwärmung des Geräts führen kann. Sorgen Sie für ausreichende Kühlung und überschreiten Sie die angegebenen Stromgrenzen nicht.

### Hinweise zur Stromversorgung
- Wird dauerhaft eine Leistungsabgabe von mehr als 1 A benötigt, wird empfohlen, den USB-C-Power-Anschluss mit einem separaten 5-V-Netzteil zu verwenden.
- In diesem Fall sind für die Summe aller Verbraucher bis zu 3 A möglich.
- Über die Klemme 1 und 2 des Steckverbinder kann die 5 V Spannung für externe Verbraucher abgenommen werden. Über die Klemme 3 wird der Schaltausgang des Kanal 1 (CH1) versorgt und über die Klemme 8 der Schaltausgang des Kanal 4 (CH4). Die Klemmen können auch für den Spannungsabgriff für die Servomotoren verwendet werden.

#### Anschlussbeispiele

Da einzelne Verbraucher, wie z. B. LED-Streifen, hohe Ströme (> 1 A) aufnehmen können, ist auch eine kombinierte Einspeisung möglich.
Beispielsweise kann die ZapBox über die DC-Buchse mit 12 V versorgt werden und gleichzeitig den Relaiskontakt am Ausgang 4 (CH4) mit dieser Spannung speisen.
Der interne Spannungswandler versorgt dabei das System (ESP32) sowie die Ausgänge 1–3 (CH1–CH3) mit 5 V, während eine 12-V-LED-Leiste am Ausgang 4 direkt mit 12 V betrieben wird. Dadurch wird die Belastung des internen Spannungswandlers reduziert.

Eine weitere häufige Anwendung ist der Betrieb von Servomotoren, die eine höhere Versorgungsspannung benötigen, z. B. HV-Servos (High Voltage) mit Spannungen zwischen 7,4 V und 8,4 V.
Hierzu wird die ZapBox über den DC-Buchseneingang beispielsweise mit 8 V versorgt. Intern wird die Spannung vor dem Spannungsregler abgegriffen und auf die dafür vorgesehene Klemme 3 sowie GND geführt. Die externe Brücke zwischen Klemme 1 und Klemme 3 muss hierfür entfernt werden.

Dadurch werden die Schaltausgänge 1 bis 3 mit 8 V versorgt und können die Servomotoren direkt antreiben. Die Strombelastung sollte dabei 3 A nicht überschreiten, da dies aktuell die Grenze der internen Verdrahtung darstellt.

Der Schaltausgang 4 kann über eine Brücke zwischen Klemme 1 und Klemme 8 mit 5 V gespeist werden. Optinal kann an Klemme 8 auch eine andere Spannung, z. B. 12 V, angeschlossen werden. Kanal 4 kann anschließend beispielsweise zum Schalten einer LED-Beleuchtung als Ambientlicht verwendet werden.

#### Zusatzinformation

Zusätzlich kann neben der DC-Versorgung (6 V–36 V) ein 5-V-Netzteil mit maximal 3 A am USB-C-Power-Anschluss angeschlossen werden.
Der gleichzeitige Betrieb beider Versorgungen ist möglich, jedoch sind Unterschiede der 5-V-Spannungen zu beachten, um gegenseitige Beeinflussung oder Rückspeisung der Netzteile zu vermeiden.

## 16-poliger Steckverbinder

Die ZapBox verfügt über einen abnehmbaren 16-poligen Steckverbinder (15EDGWC 3,81 mm).

**Klemmenbelegung in der Übersicht:**
| Klemme | Funktion | Verwendung | Hinweis |
|---|---|---|---|
| 1 | 5 V | Ausgang | Spannungsversorgung 5 V |
| 2 | GND | Ausgang | Masse |
| 3 | Versorgung Kanal 1-3 | Eingang / Ausgang | 5 V oder 6 V–36 V |
| 4 | CH1 Schaltausgang Kanal 1 (GPIO Pin 12) | Ausgang | Ansteuerung Verbraucher (NO – Normally Open) |
| 5 | CH2 Servo Steuersignal 1 (GPIO Pin 13) | Ausgang | Ansteuerung Servomotor (pulsierend, 3,3 V) |
| 6 | CH3 Servo Steuersignal 2 (GPIO Pin 11) | Ausgang | Ansteuerung Servomotor (pulsierend, 3,3 V) |
| 7 | GND | Ausgang | Masse |
| 8 | Versorgung Kanal 4 | Eingang / Ausgang | 5 V oder 6 V–36 V |
| 9 | CH4 Schaltausgang Relais Kanal 4 (GPIO Pin 11) | Ausgang | Ansteuerung Verbraucher (NO – Normally Open) |
| 10 | GND| Ausgang | Masse |
| 11 | Sensor (GPIO Pin 2) | Eingang | Für z.B. eine Lichtschranke (NPN) |
| 12 | 5 V | Ausgang | 5 V für Sensor und NFC-Modul |
| 13 | GND | Ausgang | Masse für Sensor und NFC-Modul |
| 14 | NFC IRQ (GPIO Pin 1) | Schnittstelle | Externes NFC-Modul |
| 15 | I2C SCL (GPIO Pin 17) | Schnittstelle | Externes NFC-Modul |
| 16 | I2C SDA (GPIO Pin 18) | Schnittstelle | Externes NFC-Modul |

**Hinweis zur Belegung:** 

Die Klemmenbelegung des Steckverbinders ist von rechts nach links durchnummeriert: Klemme 1 befindet sich ganz rechts, Klemme 16 ganz links. Siehe dazu Bild 2: Rückansicht.

Die ZapBox Servo verfügt über vier Ausgänge (Kanal 1 bis Kanal 4). Kanal 1 und Kanal 4 sind fest mit Relais verbunden. Kanal 2 und Kanal 3 sind direkt auf die Ausgangsklemmen geführt und hauptsächlich für die Servoansteuerung vorgesehen.
An den Ausgangsklemmen 5 und 6 liegen die Steuersignale der GPIO-Pins 13 und 10 an.

**Hinweis Spannungsverteilung mit Brücken:** 

Im Werkszustand sind die Klemmen 1 (allgemeine Versorgung) und 12 (Versorgung für Sensor und NFC-Modul) mit 5 V belegt. Die Masse (GND) ist auf den Klemmen 2, 7, 10 und 13 geführt.

Die Relaiskontakte besitzen keine interne Versorgungsspannung. Die gewünschte Schaltspannung muss daher extern aufgebrückt werden.
Um beispielsweise einen 5-V-Verbraucher zu schalten, ist für die Kanäle 1–3 eine externe Brücke auf dem 16-poligen Steckverbinder von Klemme 1 auf Klemme 3 erforderlich.
Für den Betrieb von Kanal 4 mit 5 V muss zusätzlich eine Brücke von Klemme 1 auf Klemme 8 gesetzt werden.

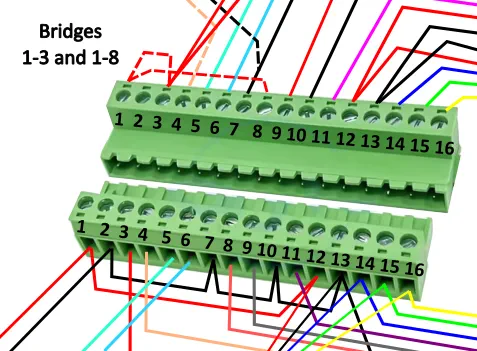
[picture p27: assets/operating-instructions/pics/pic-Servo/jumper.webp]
Jumper


*Bild 3: Auszug E-Layout - Klemmen die gebrückt sind*

**Hinweis zu DC-Buchse (6 V–36 V für Klemmen 3 & 8):** 

Die Eingangsspannung der DC-Hohlsteckerbuchse (6 V–36 V) kann intern abgegriffen und auf die Klemmen 3 und/oder 8 geführt werden, um Relaisausgänge mit höheren Spannungen zu betreiben.

**Voraussetzungen:**
- Eingriffe dürfen ausschließlich durch elektrotechnische Fachkräfte erfolgen.
- Die ggf. vorhandenen 5-V-Brücken (Klemme 1 → 3 und/oder Klemme 1 → 8) müssen **zuvor** entfernt werden.
- Details sind dem [E-Layout](https://github.com/AxelHamburch/ZapBox#electrical-layout) der ZapBox Servo zu entnehmen.

## Schaltausgänge Kanal 1 bis 4 

Die Servo verfügt über vier Relaisausgänge, die intern als Schließer (NO – Normally Open) ausgeführt und über die Klemmen 4, 5 und 6 sowie Klemme 9 des Steckverbinders nach außen geführt sind. Die Schließerkontakte sind den Kanälen 1 bis 3 jeweils den Klemmen 4, 5 und 6 zugeordnet; Kanal 4 ist auf Klemme 9 verdrahtet.

Soll ein Relaiskontakt als Öffner (NC – Normally Closed) verwendet werden, ist eine interne Umverdrahtung erforderlich.

Die Schaltausgänge sind für eine maximale Strombelastung von 3 A Dauerlast ausgelegt. Kurzzeitig sind Belastungen bis zu 5 A zulässig.

## Schnittstelle Mikrocontroller (ESP32)

### Seitenpanel öffnen
Um Daten vom Gerät zu lesen oder zu übertragen, verbinden Sie die ZapBox mit einem Computer oder Laptop:

1. An der **rechten Seite der Frontblende** befindet sich eine kleine Abdeckung.
2. Öffnen Sie die Abdeckung, indem Sie von unten mit einem **schmalen Schraubendreher** die Abdeckung nach rechts wegschieben. Bei einigen Modellen ist auf der Abdeckung eine kleine Aussparung. Diese Aussparung kann genutzt werden, um die Abdeckung nach vorne zu kippen.

### USB-C-Kabel anschließen
3. Schließen Sie ein USB-C-Kabel am darunter liegenden Anschluss des Mikrocontrollers an.

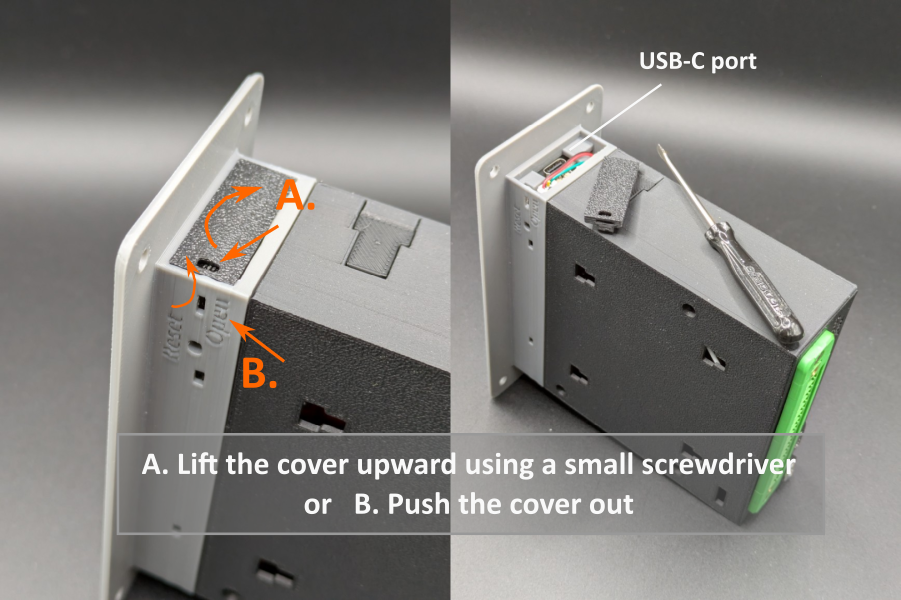
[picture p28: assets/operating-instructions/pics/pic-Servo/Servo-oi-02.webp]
Panel öffnen und USB-C-Anschluss


*Bild 4: Panel öffnen und USB-C-Anschluss für Daten*

> **Wichtiger Hinweis:** Der USB-Anschluss direkt am Mikrocontroller ist ausschließlich zum Flashen der Firmware und zur Übertragung von Konfigurationsparametern vorgesehen. Während des Flashvorgangs darf keine Last am Ausgang geschaltet werden, da dies zu Fehlfunktionen oder zur **Beschädigung des Mikrocontrollers** führen kann.
>
> Es wird daher empfohlen:
> - während der USB-Verbindung keine Last am Ausgang anzuschließen oder
> - den regulären **Power-IN-Eingang** zusätzlich an dieselbe Spannungsversorgung anzuschließen. Dadurch wird sichergestellt, dass der Strom für das Leistungsrelais nicht über den Mikrocontroller fließt und diesen überlastet.

---

## Bedienelemente

Je nach Version verfügt die ZapBox neben dem **LED-Button** über zwei **On-board-Mikrotaster**, die direkt mit dem Mikrocontroller verbunden sind. Alle Funktionen sind sowohl über den LED-Button als auch über die Mikrotaster erreichbar. Zusätzlich verfügt die ZapBox an der Unterseite des Frontpanels über einen Reset-Taster sowie optional an der Seite über einen Schiebeschalter für weitere Anwendungen.

### Funktionsübersicht - Mikrotaster / LED-Button

| Funktion | Mikrotaster | LED-Button |
|---|---|---|
| Hilfe-Seite anzeigen | 1× HELP drücken | LED-Button mind. 2 Sek. gedrückt halten |
| Nächste Seite / Produktwechsel | 1× NEXT drücken | 1× LED-Button kurz drücken |
| REPORT-Seite anzeigen | 2× HELP drücken | LED-Button 3× schnell hintereinander drücken |
| Config-Modus aufrufen | NEXT mind. 5 Sek. gedrückt halten | 1× kurz drücken, dann mind. 5 Sek. gedrückt halten |

---

## Montagehalterung mit Schnapp-Arretierung

Mit der optionalen Montagehalterung kann die ZapBox leicht montiert werden. 
Die Schnapp-Arretierung kann mit einem flachen Schraubendreher gelöst werden.

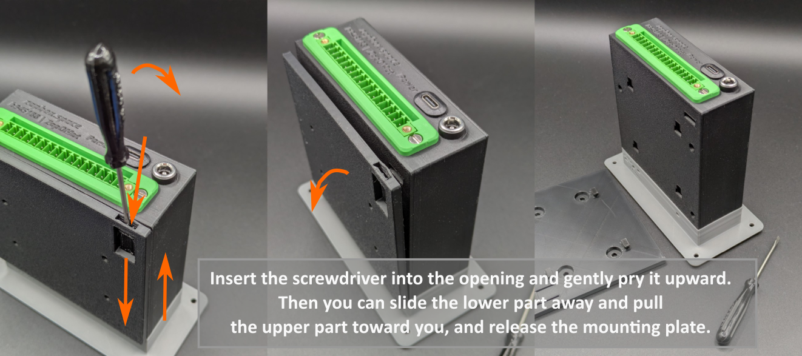
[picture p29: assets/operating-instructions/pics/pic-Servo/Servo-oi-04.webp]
Lösen der Montagehalter


*Bild 5: Lösen der Montagehalterung*

> **Hinweis:** Die ZapBox ist auf der Montagehalterung nur aufgeschoben und mit einem Schnappverschluss arretiert. Die Arretierung kann mit einem flachen Schraubendreher gelöst werden. Dazu den Schraubendreher vorsichtig in den Schlitz einschieben, leicht anheben und dabei den oberen Teil der ZapBox in Richtung des Schraubendrehers drücken. Die Verbindung sollte sich lösen und die ZapBox kann von der Montageplatte durch anheben getrennt werden.

---

## Einrichtung und Inbetriebnahme

Die ZapBox wird nach der Fertigung getestet und mit der aktuellen Firmware ausgeliefert - sie ist aber nicht parametriert. Die Software wird aktiv weiterentwickelt, daher ist es empfehlenswert, die ZapBox gleich zu Beginn einmal mit der neuesten Firmware zu bespielen und dann eine Parametrierung durchzuführen. Dafür gibt es einen komfortablen [**Web-Installer**](https://installer.zapbox.space/).

### Schritt 1: Firmware-Update
1. Öffnet das rechte Seitenpanel der Frontblende, wie oben unter "Seitenpanel öffnen" beschrieben.
2. Schließt die ZapBox an dem USB-C-Port mit einem Kabel an und verbindet es mit einem Computer.
3. Öffnet einen Chromium Browser, zum Beispiel Google Chrome, Microsoft Edge, Brave, Vivaldi, Opera oder [Helium](https://helium.computer/).

### Schritt 2: Parametrierung
1. Navigiert im Browser zur Web-Installer-Seite.
2. Folgt den Anweisungen auf der Seite, um die gewünschten Parameter wie `WiFi SSID`, `WiFi Passwort` und `Device Settings String` einzugeben.
3. Speichert die Einstellungen und startet die ZapBox neu.

> **Hinweis:** Während der Einrichtung sollte keine Last an den Ausgängen angeschlossen sein, um Fehlfunktionen oder Schäden am Mikrocontroller zu vermeiden.

Die ZapBox wird nach der Initialisierung den QR-Code des Produkts anzeigen und ist bereit für die erste Zahlung und anschließende Schaltaktion.

### Fehlerdiagnose und -behebung 

Die ZapBox verfügt über eine komfortable Fehleranzeige über das Display. Es gibt vier grundlegende Fehler, die priorisiert sind:

| Prio. | Fehlerart | Abkürzung | Erkennungsmethode | Beschreibung |
|---|---|---|---|---|
| 1 | **NO WIFI** | NW | WiFi-Verbindungsstatus | WiFi-Netzwerk nicht verbunden<br>-> Sind die WiFi-Daten korrekt?<br>-> Ist das WiFi-Signal zu schwach? |
| 2 | **NO INTERNET** | NI | HTTP-Check zu Google | Internetverbindung verloren<br>-> Ist das Internet erreichbar? |
| 3 | **NO SERVER** | NS | TCP-Port 443-Check | LNbits-Server nicht erreichbar<br>-> Ist die Server-Hardware ausgefallen?<br>-> Ist der Geräte-String korrekt? |
| 4 | **NO WEBSOCKET** | NWS | WebSocket-Verbindungsstatus | WebSocket-Protokoll-/Handshake-Fehler<br>-> Ist LNbits ausgefallen?<br>-> Ist der Geräte-String korrekt? |

Die Fehlermeldungen werden auch geloggt und können über den *Report Mode* abgerufen werden:

- Drücken Sie die HELP-Taste zweimal schnell hintereinander, um Fehlerzähler (0-99) für alle vier Fehlertypen mit ihren Auftretenshäufigkeiten anzuzeigen.
- Drücken Sie die LED-Taste dreimal schnell hintereinander (falls eine externe LED-Taste verfügbar ist).

Weitere aktuelle Informationen zu Fehlerbeschreibungen können auf der Web-Installer-Seite in den Kapiteln "Error Detection & Report" und "Troubleshoot" nachgelesen werden. 

---

## NFC-Modul (Option)

Je nach Ausstattung verfügt die ZapBox über ein NFC-Modul, das entweder auf der Oberseite montiert ist oder über den 16-poligen Steckverbinder extern als separates Modul verwendet werden kann.

Die ZapBox unterstützt aktuell folgende Kartentypen:

- **Boltcards** (NTAG424 DNA)
- **LNURL-Withdraw** von NTAG21x (213 / 215 / 216)

Voraussetzung für die Funktion ist die LNbits [ZapBox Extension](https://github.com/AxelHamburch/zapbox_extension). Diese muss vom LNbits-Server unterstützt werden. 

---

## Technische Daten

| Eigenschaft | Wert |
|---|---|
| Versorgungsspannung | 5V DC über USB-C, max. 3A |
| Versorgungsspannung | 6V–36V über DC-Hohlbuchse, max. 3A bei 24V |
| DC-DC Spannungswandler | 6V–36V → 5V, max. 1A Dauerlast, 2A kurzzeitig (2,5A Spitze) |
| Schaltausgänge Relais | Max. 3A Dauerlast (kurzzeitig 5A) |
| Display | 1,9" LCD (T-Display-S3) |
| NFC-Modul | PN532 |
| Temperaturbereich | 0–40 °C |
| Kommunikation | Wi-Fi (ESP32-S3) |
| Zahlungsprotokoll | Bitcoin Lightning Network |

---

## Sicherheitshinweise

- Betreiben Sie das Gerät ausschließlich mit der angegebenen Versorgungsspannung.
- Überschreiten Sie nicht die maximalen Strombelastungen der Ausgänge.
- Führen Sie keine Arbeiten an den Relaiskontakten unter Last durch.
- Das Gerät ist nicht für den Einsatz in feuchten oder nassen Umgebungen geeignet.
- Sorgen Sie für ausreichende Belüftung um das Gerät. 
- Außerhalb der Reichweite von Kindern aufbewahren.

---

## Weiterführende Links

| Ressource | Link |
|---|---|
| Übersicht aller ZapBox-Modelle | https://zapbox.space/ |
| Web-Installer, Kurzübersicht & Fehlerbehebung | https://installer.zapbox.space/ |
| Detaillierte Dokumentation (Parameter & Funktionen) | https://ereignishorizont.xyz/zapbox/ |
| GitHub-Repository (Software, 3D-Druckdateien, Anleitungen, etc.) | https://github.com/AxelHamburch/ZapBox |
| GitHub-Repository (E-Layouts) | https://github.com/AxelHamburch/ZapBox#electrical-layout |
| ZapBox Extension | https://github.com/AxelHamburch/zapbox_extension |
| LNbits | https://lnbits.com/ |

---

*Änderungen und Irrtümer vorbehalten. Stand: 2026*

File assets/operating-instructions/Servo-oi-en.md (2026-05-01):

# ZapBox Servo – User Manual

**Language:** English | **Version:** oi947394

---

## Table of Contents

1. [Introduction](#introduction)
2. [Standard Equipment](#standard-equipment)
3. [Power Supply](#power-supply)
4. [16-Pin Connector](#16-pin-connector)
5. [Switching Outputs Channels 1 to 4](#switching-outputs-channels-1-to-4)
6. [Microcontroller Interface (ESP32)](#microcontroller-interface-esp32)
7. [Controls](#controls)
8. [Mounting Bracket with Snap Lock](#mounting-bracket-with-snap-lock)
9. [Setup and Commissioning](#setup-and-commissioning)
10. [NFC Module (Option)](#nfc-module-option)
11. [Technical Specifications](#technical-specifications)
12. [Safety Instructions](#safety-instructions)
13. [Further Links](#further-links)

---

## Introduction

The **ZapBox Servo** is an electronic switch for Bitcoin Lightning payments. A payment via the Lightning Network can trigger switching outputs – ideal for vending machines, presentations, event control, and many other applications.

For comprehensive automation tasks, the contacts are routed externally via a 16-pin removable connector. The device also features an additional sensor input that can be individually configured. Optionally, the NFC module can be routed externally via the connector strip.

For versatile use and easy connection, the Servo can be powered either via the 5 V USB-C port or via a DC barrel jack power supply. It features a wide-range input (DC 6–36 V) with a standard DC barrel socket (5.5 × 2.1 mm).
The required 5 V supply is generated internally via a self-regulating voltage converter. This significantly expands the range of applications, and the power supply for the outputs can be provided internally, independent of the 5 V supply.

Front view

*Figure 1: Front view and rear view*

Rear view

*Figure 1: Rear view*

## Standard Equipment

| Component | Description |
|---|---|
| Microcontroller | T-Display-S3 with 1.9" LCD display |
| Front panel | Available with 35° or 90° display front (90° also available for panel mounting) |
| Power supply | USB-C (5 V) and wide-range input DC 6 V–36 V (barrel socket 5.5 × 2.1 mm) |
| Inputs / Outputs | 16-pin connector (15EDGWC 3.81 mm) |
| Outputs | 2 relay outputs CH1/CH4 – switching contacts (NO/COM/NC) |
| Outputs | 2 control outputs CH2/CH3 – GPIO outputs for servo control |
| Input | 1 sensor input |
| Interface | Connection for external NFC module |
| Control | LED button (full ZapBox functionality) |
| Option BTC ticker | Activatable via the Web Installer |
| Option board buttons | Two on-board micro buttons (optionally concealed) |
| Option NFC module | For Bolt Cards (NTAG424 DNA) and standard NTAG213/215/216 (with LNURL-withdraw) |
| Option switch | Slide switch (ON/OFF) |

---

## Power Supply

The ZapBox Servo features a USB-C port as well as a DC barrel socket (5.5 × 2.1 mm) for common DC plug-in power supplies.
The power supply for the outputs can be individually adapted: either externally via terminals 3 and 8, or internally by tapping the supply voltage of the wide-range input.

### USB-C Power Input (5 V)

The ZapBox can be powered via the USB-C **Power** port with **5 V DC (max. 3 A)**. The 5 V supply is routed to the outside via terminal 1 of the connector and can be bridged there to terminals 3 and 8 to supply the switching outputs.

> **Note:** The USB power port does not support automatic USB-C power negotiation (no USB-C Power Delivery). Some USB-C chargers or power modules may therefore not recognize the ZapBox as a load and will not supply power. In this case, use a **USB-A output** of the power supply or an alternative 5 V power source. The maximum current must not exceed 3 A.

### DC Barrel Socket Power Input (6 V–36 V)

The DC barrel socket is designed as a wide-range input for voltages from 6 V to 36 V and is suitable for common power supplies with, for example, 12 V or 24 V output voltage.
The input voltage is regulated internally via a step-down converter to 5 V. The voltage converter can deliver up to 1 A in continuous operation. **Heat generation must be taken into account ⚠️.**
Currents of up to 2 A are also possible briefly, and up to 2.5 A in very short load peaks.

Internally, it is possible to tap the input voltage and wire it to the connector strip to supply the output channels directly with the input voltage. This requires opening the device and must only be performed by qualified electricians. Details are described in the [E-Layout](https://github.com/AxelHamburch/ZapBox#electrical-layout) of the ZapBox Servo.

> **Note:** The internal voltage converter has limited capacity. High load currents generate increased heat dissipation, which may cause the device to heat up. Ensure adequate cooling and do not exceed the specified current limits.

### Power Supply Notes
- If a continuous power output of more than 1 A is required, it is recommended to use the USB-C power port with a separate 5 V power supply.
- In this case, up to 3 A is possible for the sum of all loads.
- The 5 V supply voltage for external loads can be tapped at terminals 1 and 2 of the connector. Terminal 3 supplies the switching output of channel 1 (CH1) and terminal 8 supplies the switching output of channel 4 (CH4). These terminals can also be used as supply voltage taps for servo motors.

#### Wiring Examples

Since individual loads, such as LED strips, can draw high currents (> 1 A), a combined feed is also possible.
For example, the ZapBox can be supplied with 12 V via the DC socket and simultaneously feed the relay contact at output 4 (CH4) with this voltage.
The internal voltage converter then supplies the system (ESP32) and outputs 1–3 (CH1–CH3) with 5 V, while a 12 V LED strip at output 4 is operated directly at 12 V. This reduces the load on the internal voltage converter.

Another common application is the operation of servo motors that require a higher supply voltage, e.g. HV servos (High Voltage) with voltages between 7.4 V and 8.4 V.
For this, the ZapBox is supplied, for example, with 8 V via the DC barrel input. Internally, the voltage is tapped before the voltage regulator and routed to the designated terminal 3 and GND. The external bridge between terminal 1 and terminal 3 must be removed for this purpose.

This supplies switching outputs 1 to 3 with 8 V and allows them to drive servo motors directly. The current load should not exceed 3 A, as this is currently the limit of the internal wiring.

Switching output 4 can be supplied with 5 V via a bridge between terminal 1 and terminal 8. Optionally, a different voltage, e.g. 12 V, can also be connected to terminal 8. Channel 4 can then be used, for example, to switch LED ambient lighting.

#### Additional Information

In addition to the DC supply (6 V–36 V), a 5 V power supply with a maximum of 3 A can be connected to the USB-C power port simultaneously.
Operating both supplies at the same time is possible, but differences in the 5 V voltages must be taken into account to avoid mutual interference or back-feeding of the power supplies.

## 16-Pin Connector

The ZapBox features a removable 16-pin connector (15EDGWC 3.81 mm).

**Terminal assignment overview:**
| Terminal | Function | Direction | Note |
|---|---|---|---|
| 1 | 5 V | Output | 5 V power supply |
| 2 | GND | Output | Ground |
| 3 | Supply channels 1–3 | Input / Output | 5 V or 6 V–36 V |
| 4 | CH1 switching output channel 1 (GPIO pin 12) | Output | Load control (NO – Normally Open) |
| 5 | CH2 servo control signal 1 (GPIO pin 13) | Output | Servo motor control (pulsed, 3.3 V) |
| 6 | CH3 servo control signal 2 (GPIO pin 11) | Output | Servo motor control (pulsed, 3.3 V) |
| 7 | GND | Output | Ground |
| 8 | Supply channel 4 | Input / Output | 5 V or 6 V–36 V |
| 9 | CH4 switching output relay channel 4 (GPIO pin 11) | Output | Load control (NO – Normally Open) |
| 10 | GND | Output | Ground |
| 11 | Sensor (GPIO pin 2) | Input | E.g. for a light barrier (NPN) |
| 12 | 5 V | Output | 5 V for sensor and NFC module |
| 13 | GND | Output | Ground for sensor and NFC module |
| 14 | NFC IRQ (GPIO pin 1) | Interface | External NFC module |
| 15 | I2C SCL (GPIO pin 17) | Interface | External NFC module |
| 16 | I2C SDA (GPIO pin 18) | Interface | External NFC module |

**Note on terminal numbering:**

The terminals of the connector are numbered from right to left: terminal 1 is on the far right, terminal 16 on the far left. See Figure 2: Rear view.

The ZapBox Servo has four outputs (channel 1 to channel 4). Channels 1 and 4 are permanently connected to relays. Channels 2 and 3 are routed directly to the output terminals and are primarily intended for servo control.
The control signals of GPIO pins 13 and 10 are present at output terminals 5 and 6.

**Note on voltage distribution with bridges:**

In the factory default state, terminals 1 (general supply) and 12 (supply for sensor and NFC module) carry 5 V. Ground (GND) is routed to terminals 2, 7, 10, and 13.

The relay contacts have no internal supply voltage. The desired switching voltage must therefore be bridged externally.
To switch a 5 V load, for example, an external bridge on the 16-pin connector from terminal 1 to terminal 3 is required for channels 1–3.
To operate channel 4 with 5 V, an additional bridge from terminal 1 to terminal 8 must be set.

Jumper

*Figure 3: E-layout excerpt – terminals that are bridged*

**Note on DC barrel socket (6 V–36 V for terminals 3 & 8):**

The input voltage of the DC barrel socket (6 V–36 V) can be tapped internally and routed to terminals 3 and/or 8 to operate relay outputs at higher voltages.

**Requirements:**
- Modifications must only be carried out by qualified electricians.
- Any existing 5 V bridges (terminal 1 → 3 and/or terminal 1 → 8) must be **removed beforehand**.
- Details can be found in the [E-Layout](https://github.com/AxelHamburch/ZapBox#electrical-layout) of the ZapBox Servo.

## Switching Outputs Channels 1 to 4

The Servo features four relay outputs, internally configured as normally open (NO) contacts, routed externally via terminals 4, 5, and 6 as well as terminal 9 of the connector. The normally open contacts of channels 1 to 3 are assigned to terminals 4, 5, and 6 respectively; channel 4 is wired to terminal 9.

If a relay contact is to be used as a normally closed (NC) contact, internal rewiring is required.

The switching outputs are rated for a maximum continuous current load of 3 A. Short-term loads of up to 5 A are permissible.

## Microcontroller Interface (ESP32)

### Opening the Side Panel
To read data from or transfer data to the device, connect the ZapBox to a computer or laptop:

1. On the **right side of the front panel**, there is a small cover.
2. Open the cover by sliding it to the right from below using a **narrow screwdriver**. On some models, the cover has a small notch that can be used to tilt the cover forward.

### Connecting the USB-C Cable
3. Connect a USB-C cable to the connector on the microcontroller underneath.

Opening panel and USB-C connection

*Figure 4: Opening the panel and USB-C connection for data*

> **Important note:** The USB port directly on the microcontroller is intended exclusively for flashing firmware and transferring configuration parameters. No load must be switched on the output during the flashing process, as this may cause malfunctions or **damage to the microcontroller**.
>
> It is therefore recommended to:
> - not connect any load to the output during the USB connection, or
> - additionally connect the regular **Power IN input** to the same power supply. This ensures that the current for the power relay does not flow through the microcontroller and overload it.

---

## Controls

Depending on the version, the ZapBox features two **on-board micro buttons** in addition to the **LED button**, both directly connected to the microcontroller. All functions are accessible via either the LED button or the micro buttons. The ZapBox also features a reset button on the underside of the front panel and optionally a slide switch on the side for additional applications.

### Function Overview – Micro Buttons / LED Button

| Function | Micro button | LED button |
|---|---|---|
| Show help page | Press HELP 1× | Hold LED button for at least 2 sec. |
| Next page / product change | Press NEXT 1× | Press LED button 1× briefly |
| Show REPORT page | Press HELP 2× | Press LED button 3× in quick succession |
| Enter config mode | Hold NEXT for at least 5 sec. | Press 1× briefly, then hold for at least 5 sec. |

---

## Mounting Bracket with Snap Lock

With the optional mounting bracket, the ZapBox can be easily mounted.
The snap lock can be released with a flat screwdriver.

Releasing the mounting bracket

*Figure 5: Releasing the mounting bracket*

> **Note:** The ZapBox is only slid onto the mounting bracket and secured with a snap lock. The lock can be released with a flat screwdriver. To do this, carefully insert the screwdriver into the slot, lift slightly, and press the upper part of the ZapBox towards the screwdriver. The connection should release and the ZapBox can be separated from the mounting plate by lifting it.

---

## Setup and Commissioning

The ZapBox is tested after production and shipped with the current firmware – but it is not yet configured. The software is under active development, so it is recommended to flash the ZapBox with the latest firmware right at the start and then carry out the configuration. There is a convenient [**Web Installer**](https://installer.zapbox.space/) for this purpose.

### Step 1: Firmware Update
1. Open the right side panel of the front panel as described above under "Opening the Side Panel".
2. Connect the ZapBox to the USB-C port with a cable and connect it to a computer.
3. Open a Chromium-based browser, for example Google Chrome, Microsoft Edge, Brave, Vivaldi, Opera, or [Helium](https://helium.computer/).

### Step 2: Configuration
1. Navigate to the Web Installer page in the browser.
2. Follow the instructions on the page to enter the desired parameters such as `WiFi SSID`, `WiFi password`, and `Device Settings String`.
3. Save the settings and restart the ZapBox.

> **Note:** During setup, no load should be connected to the outputs to avoid malfunctions or damage to the microcontroller.

After initialization, the ZapBox will display the QR code of the product and is ready for the first payment and subsequent switching action.

### Troubleshooting

The ZapBox features a convenient error display via the screen. There are four fundamental errors, listed in order of priority:

| Priority | Error type | Abbreviation | Detection method | Description |
|---|---|---|---|---|
| 1 | **NO WIFI** | NW | WiFi connection status | WiFi network not connected<br>-> Is the WiFi data correct?<br>-> Is the WiFi signal too weak? |
| 2 | **NO INTERNET** | NI | HTTP check to Google | Internet connection lost<br>-> Is the internet reachable? |
| 3 | **NO SERVER** | NS | TCP port 443 check | LNbits server not reachable<br>-> Has the server hardware failed?<br>-> Is the device string correct? |
| 4 | **NO WEBSOCKET** | NWS | WebSocket connection status | WebSocket protocol/handshake error<br>-> Is LNbits down?<br>-> Is the device string correct? |

Error messages are also logged and can be retrieved via *Report Mode*:

- Press the HELP button twice in quick succession to display error counters (0–99) for all four error types with their frequency of occurrence.
- Press the LED button three times in quick succession (if an external LED button is available).

Further up-to-date information on error descriptions can be found on the Web Installer page in the sections "Error Detection & Report" and "Troubleshoot".

---

## NFC Module (Option)

Depending on the configuration, the ZapBox features an NFC module that is either mounted on the top or can be used externally as a separate module via the 16-pin connector.

The ZapBox currently supports the following card types:

- **Bolt Cards** (NTAG424 DNA)
- **LNURL-Withdraw** from NTAG21x (213 / 215 / 216)

A prerequisite for this functionality is the LNbits [ZapBox Extension](https://github.com/AxelHamburch/zapbox_extension), which must be supported by the LNbits server.

---

## Technical Specifications

| Property | Value |
|---|---|
| Supply voltage | 5 V DC via USB-C, max. 3 A |
| Supply voltage | 6 V–36 V via DC barrel socket, max. 3 A at 24 V |
| DC-DC voltage converter | 6 V–36 V → 5 V, max. 1 A continuous, 2 A briefly (2.5 A peak) |
| Relay switching outputs | Max. 3 A continuous (5 A briefly) |
| Display | 1.9" LCD (T-Display-S3) |
| NFC module | PN532 |
| Operating temperature | 0–40 °C |
| Communication | Wi-Fi (ESP32-S3) |
| Payment protocol | Bitcoin Lightning Network |

---

## Safety Instructions

- Operate the device exclusively with the specified supply voltage.
- Do not exceed the maximum current ratings of the outputs.
- Do not perform any work on the relay contacts under load.
- The device is not suitable for use in humid or wet environments.
- Ensure adequate ventilation around the device. Do not block the ventilation openings and avoid installing the device in enclosed, poorly ventilated enclosures. At higher continuous loads or elevated ambient temperatures, additional active cooling may be required.
- Keep out of reach of children.

---

## Further Links

| Resource | Link |
|---|---|
| Overview of all ZapBox models | https://zapbox.space/ |
| Web Installer, quick overview & troubleshooting | https://installer.zapbox.space/ |
| Detailed documentation (parameters & functions) | https://ereignishorizont.xyz/zapbox/ |
| GitHub repository (software, 3D print files, manuals, etc.) | https://github.com/AxelHamburch/ZapBox |
| GitHub repository (E-layouts) | https://github.com/AxelHamburch/ZapBox#electrical-layout |
| ZapBox Extension | https://github.com/AxelHamburch/zapbox_extension |
| LNbits | https://lnbits.com/ |

---

*Subject to changes and errors. As of: 2026*

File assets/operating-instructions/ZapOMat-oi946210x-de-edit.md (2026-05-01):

# ZapBox ZapOMat – Bedienungsanleitung

**Sprache:** Deutsch | **Version:** oi946210

---

## Inhaltsverzeichnis

1. [Einleitung](#einleitung)
2. [Spannungsversorgung](#spannungsversorgung)
3. [Externe Anschlüsse – 16-poliger Steckverbinder](#externe-anschlüsse--16-poliger-steckverbinder)
4. [USB-C-Anschluss](#usb-c-anschluss)
5. [Schaltausgänge Kanal 1 bis 4](#schaltausgänge-kanal-1-bis-4)
6. [Bedienelemente](#bedienelemente)
7. [Montagehalterung mit Schnapp-Arretierung](#montagehalterung-mit-schnapp-arretierung) 
8. [Einrichtung und Inbetriebnahme](#einrichtung-und-inbetriebnahme)
9. [NFC-Modul (Option)](#nfc-modul-option)
10. [Technische Daten](#technische-daten)
11. [Sicherheitshinweise](#sicherheitshinweise)
12. [Weiterführende Links](#weiterführende-links)

---

## Einleitung

Die **ZapBox ZapOMat** ist ein elektronischer Schalter für Bitcoin-Lightning-Zahlungen. Mit einer Zahlung über das Lightning-Netzwerk lassen sich Ausgänge schalten – ideal für Automaten, Präsentationen, Eventsteuerung und viele weitere Anwendungen. 

Für umfängliche Automatisierungsaufgaben sind die Kontakte über einen 16-poligen abnehmbaren Steckverbinder nach außen geführt. Sie verfügt über einen zusätzlichen Sensoreingang, der individuell parametriert werden kann. Optional kann das NFC-Modul über die Steckerleiste extern geführt werden. 

Für den industriellen Einsatz und komfortablen Anschluss kann die ZapOMat, alternativ zum 5V USB-C-Anschluss, mit einem DC-Steckernetzteil betrieben werden. Die ZapOMat kann dafür optional mit einem Weitbereichseingang (DC 6V–36V) über eine Standard 5,5×2,1 mm DC-Buchse angeschlossen werden. Für die intern benötigten 5V ist ein Spannungswandler vorhanden, der selbstregulierend ist. Das erweitert die Anwendungsmöglichkeiten enorm und die Spannungsversorgung für die Ausgänge kann dementsprechend angepasst werden.

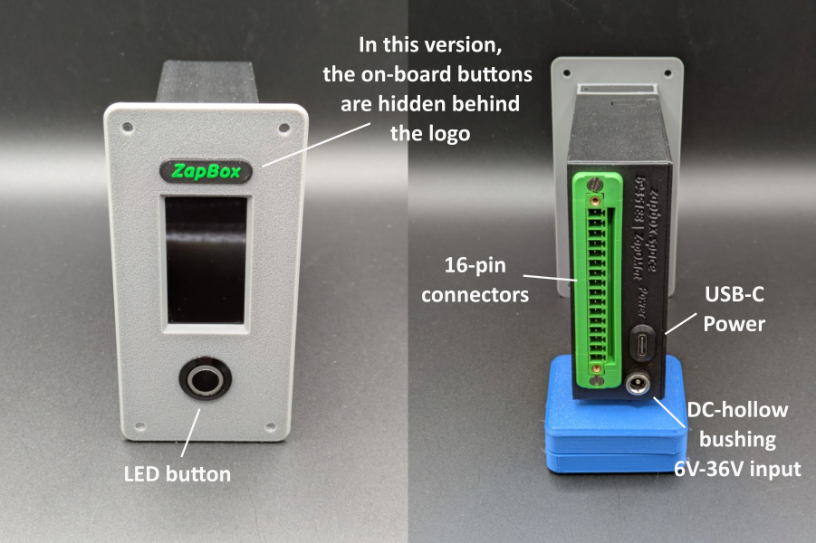
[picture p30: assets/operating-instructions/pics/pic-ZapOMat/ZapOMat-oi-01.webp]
Frontansicht


*Bild 1: Frontansicht und Rückansicht*

## Grundausstattung

| Komponente | Beschreibung |
|---|---|
| Mikrocontroller | T-Display-S3 mit 1,9" LCD-Display |
| Frontpanel | Wahlweise mit 35° oder 90° Display Front (90° auch Einbau erhältlich) |
| Spannungsversorgung | USB-C (5V) und Weitbereichseingang DC 6V-36V (Hohlbuchse 5,5*2,1 mm) |
| Eingänge / Ausgänge | 16-polige Steckverbinder (15EDGWC 3,81mm) |
| Ausgänge | 4 Relaisausgänge CH1-CH4 - Schaltkontakte (NO/COM/NC) |
| Eingang | 1 Sensoreingang |
| Interface | Anschluss für externes NFC-Modul |
| Bedienelement | LED-Button (volle ZapBox-Funktionalität) |
| Option BTC-Ticker | Aktivierbar über den Web Installer |
| Option Boardtaster | Zwei On-board-Mikrotaster (optional verdeckt)|
| Option NFC-Modul | Für Bolt Cards (NTAG424 DNA) und Standard NTAG213/215/216 (mit LNURL-withdraw) |
| Option Schalter | Schiebeschalter (ON/OFF) |

---

## Spannungsversorgung

Die ZapBox ZapOMat verfügt über einen USB-C-Anschluss sowie über eine DC-Hohlsteckerbuchse (5,5 × 2,1 mm) für gängige DC-Steckernetzteile.

### USB-C-Anschluss
Der USB-C-Anschluss ermöglicht die Stromversorgung mit 5 V und eignet sich für einfache Anwendungen und einem Strombedarf bis max. 3 Ampere.

### DC-Hohlsteckerbuchse
Die DC-Buchse ist als Weitbereichseingang für Spannungen von 6 V bis 36 V ausgelegt. Die Eingangsspannung wird intern über einen Step-Down-Converter auf 5 V geregelt. Der Spannungswandler kann im Dauerbetrieb bis zu 1 A liefern. **Die Wärmeentwicklung ist dabei zu beachten ⚠️.** Kurzzeitig sind auch 2 A möglich, in sehr kurzen Lastspitzen bis zu 2,5 A.

### Hinweise zur Stromversorgung
- Wird dauerhaft eine Leistungsabgabe von mehr als 1 A benötigt, wird empfohlen, den USB-C-Power-Anschluss mit einem separaten 5-V-Netzteil zu verwenden.
- In diesem Fall sind für die Summe aller Verbraucher bis zu 3 A möglich.

Da einzelne Verbraucher, wie z. B. LED-Streifen, hohe Ströme (> 1 A) aufnehmen können, ist auch eine kombinierte Einspeisung möglich. Beispielsweise kann die ZapBox über die DC-Buchse mit 12 V versorgt werden und gleichzeitig den Relaiskontakt am Ausgang 4 mit dieser Spannung speisen. Der interne Spannungswandler versorgt dabei das System sowie die Relaisausgänge 1–3 mit 5 V, während eine 12-V-LED-Leiste am Ausgang 4 direkt mit 12 V betrieben wird. Dadurch wird die Belastung des internen Spannungswandlers reduziert.

Eine weitere oft benötigte Variante ist der Betrieb von 24V Motoren an den Schaltausgängen. Dazu wird die ZapBox an dem DC-Buchseneingang mit 24V versorgt und intern die Spannung vor dem Spannungsregler abgegriffen und auf die dafür vorgesehene Klemme 3 und GND verdrahtet. Die externe Brücke zwischen Klemme 1 und Klemme 3 muss dafür entfallen. Damit sind die Schaltausgänge 1 bis 3 mit 24V gespeist und können 24V Motoren antreiben. In Summe aber nicht mehr als 3 Ampere. Der Schaltausgang 4 kann mit einer Brücke zwischen 1 und 8 mit 5 V gespeist werden. Damit kann der Kanal 4 dann z.B. für ein LED-Licht als Ambientlicht für den Hintergrund geschaltet werden.

Zusätzlich kann neben der DC-Versorgung (6 V–36 V) ein 5-V-Netzteil mit maximal 3 A am USB-C-Power-Anschluss angeschlossen werden.
Der gleichzeitige Betrieb beider Versorgungen ist möglich, jedoch sind Unterschiede der 5-V-Spannungen zu beachten, um gegenseitige Beeinflussung oder Rückspeisung der Netzteile zu vermeiden.

### Spannungseingang USB-C Buchse (5V) 

Die ZapBox kann über den USB-C-Anschluss **Power** mit **5 V DC (max. 3 A)** versorgt werden. Über diesen Anschluss können die 5 V ebenfalls abgegriffen werden, wenn die Spannungsversorgung über die DC-Hohlsteckerbuchse erfolgt.

> **Hinweis:** Der USB-Power-Anschluss unterstützt keine automatische USB-C-Leistungsanforderung (kein USB-C Power Delivery). Einige USB-C-Ladegeräte oder Powermodule erkennen die ZapBox daher nicht als Verbraucher und liefern keinen Strom. Verwenden Sie in diesem Fall einen **USB-A-Ausgang** der Spannungsversorgung oder eine alternative 5-V-Stromquelle. Die maximale Stromstärke darf 3 A nicht überschreiten.

### Spannungseingang DC-Hohlsteckerbuchse (6 V–36 V)

Die DC-Buchse ist für Hohlstecker des Typs 5,5 × 2,1 mm ausgelegt und eignet sich für gängige Netzteile, z. B. mit 12 V oder 24 V Ausgangsspannung.

Intern besteht die Möglichkeit, die Eingangsspannung abzugreifen und auf die Steckerleiste zu verdrahten, um die Ausgangskanäle direkt mit der Eingangsspannung zu versorgen. Dies erfordert einen Eingriff in das Gerät und darf ausschließlich von elektrotechnischen Fachkräften durchgeführt werden. Details hierzu sind im [E-Layout](https://github.com/AxelHamburch/ZapBox#electrical-layout) der ZapBox ZapOMat beschrieben.

> **Hinweis:** Der interne Spannungswandler besitzt eine begrenzte Leistungsfähigkeit. Bei hohen Lastströmen entsteht erhöhte Wärmeentwicklung, die zu einer Erwärmung des Geräts führen kann. Sorgen Sie für ausreichende Kühlung und überschreiten Sie die angegebenen Stromgrenzen nicht.

## Externe Anschlüsse – 16-poliger Steckverbinder

Die ZapBox verfügt über einen abnehmbaren 16-poligen Steckverbinder.

**Klemmenbelegung in der Übersicht:**
| Klemme | Funktion | Verwendung | Hinweis |
|---|---|---|---|
| 1 | 5 V | Ausgang | Spannungsversorgung 5 V |
| 2 | GND | Ausgang | Masse / 0 V |
| 3 | Versorgung Kanal 1-3 | Eingang / Ausgang | 5 V oder 6 V–36 V |
| 4 | Schaltkontakt (NO) Relais Kanal 1 | Ausgang | Ansteuerung Verbraucher (NO – Normally Open) |
| 5 | Schaltkontakt (NO) Relais Kanal 2 | Ausgang | Ansteuerung Verbraucher (NO – Normally Open) |
| 6 | Schaltkontakt (NO) Relais Kanal 3 | Ausgang | Ansteuerung Verbraucher (NO – Normally Open) |
| 7 | GND | Ausgang | Masse / 0 V  |
| 8 | Versorgung Kanal 4 | Eingang / Ausgang | 5 V oder 6 V–36 V |
| 9 | Schaltkontakt (NO) Relais Kanal 4 | Ausgang | Ansteuerung Verbraucher (NO – Normally Open) |
| 10 | GND| Ausgang | Masse / 0 V |
| 11 | Sensor (GPIO Pin 2) | Eingang | Für z.B. eine Lichtschranke (NPN) |
| 12 | 5 V | Ausgang | 5 V für Sensor und NFC-Modul |
| 13 | GND | Ausgang | Masse für Sensor und NFC-Modul |
| 14 | NFC IRQ (GPIO Pin 1) | Schnittstelle | Externes NFC-Modul |
| 15 | I2C SCL (GPIO Pin 17) | Schnittstelle | Externes NFC-Modul |
| 16 | I2C SDA (GPIO Pin 18) | Schnittstelle | Externes NFC-Modul |

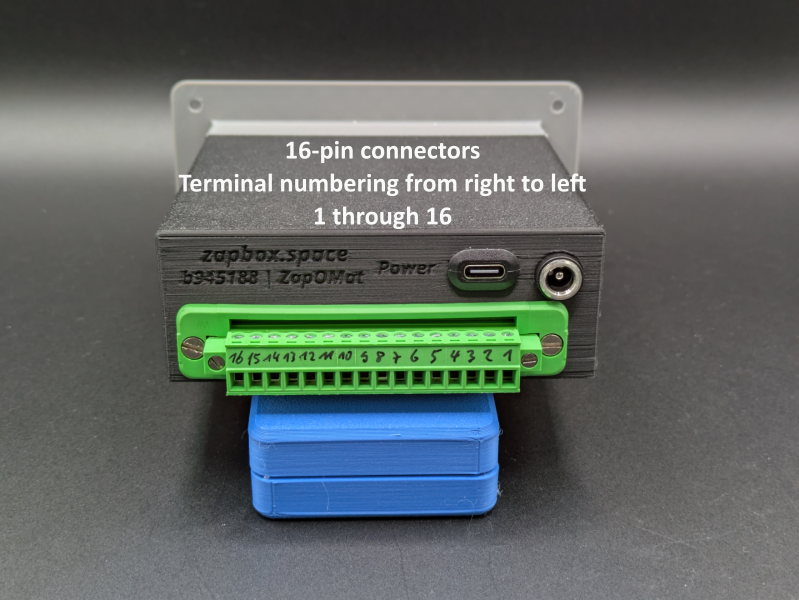
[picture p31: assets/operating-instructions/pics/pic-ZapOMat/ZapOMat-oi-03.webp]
Draufsicht


*Bild 2: Reihenfolge Klemmenbelegung Steckverbinder, von rechts nach links*

**Hinweis Spannungsverteilung mit Brücken:** 

Im Werkszustand werden die Klemmen 1 (Versorgung Allgemein) und 12 (Versorgung Sensor und NFC-Modul) mit 5 V belegt. Die Masse (GND) ist auf den Klemmen 2, 7, 10 und 13 verdrahtet. 

Die Relaiskontakte besitzen keine interne Versorgungsspannung. Die gewünschte Schaltspannung muss extern aufgebrückt werden. Um beispielsweise einen 5-V-Verbraucher zu schalten, muss für die Kanäle 1–3 eine externe Brücke (auf dem 16-poligen Steckverbinder) von Klemme 1 auf Klemme 3 gesetzt werden. Für den Betrieb von Kanal 4 mit 5 V ist eine Brücke von Klemme 1 auf Klemme 8 erforderlich.

**Hinweis zu den Relaiskontakten:** 

Die Relaiskontakte sind intern als Schließer (NO – Normally Open) ausgeführt und über die Klemmen 4, 5 und 6 sowie Klemme 9 nach außen geführt. Soll ein Relaiskontakt als Öffner (NC – Normally Closed) verwendet werden, ist eine interne Umverdrahtung erforderlich.

**Hinweis zu DC-Buchse (6 V–36 V für Klemmen 3 & 8):** 

Die Eingangsspannung der DC-Hohlsteckerbuchse (6 V–36 V) kann intern abgegriffen und auf die Klemmen 3 und/oder 8 geführt werden, um Relaisausgänge mit höheren Spannungen zu schalten.

**Voraussetzungen:**
- Eingriffe dürfen ausschließlich durch elektrotechnische Fachkräfte erfolgen.
- Die ggf. vorhandenen 5-V-Brücken (Klemme 1 → 3 und/oder Klemme 1 → 8) müssen **zuvor** entfernt werden.
- Details sind dem [E-Layout](https://github.com/AxelHamburch/ZapBox#electrical-layout) der ZapBox ZapOMat zu entnehmen.

## USB-C-Anschluss

### Seitenpanel öffnen
Um Daten vom Gerät zu lesen oder zu übertragen, verbinden Sie die ZapBox mit einem Computer oder Laptop:

1. An der **rechten Seite der Frontblende** befindet sich eine kleine Abdeckung.
2. Öffnen Sie die Abdeckung, indem Sie von unten mit einem **schmalen Schraubendreher** die Abdeckung nach rechts wegschieben. Bei einigen Modellen ist auf der Abdeckung eine kleine Aussparung. Diese Aussparung kann genutzt werden, um die Abdeckung nach vorne zu kippen.

### Anschluss des USB-C-Kabels
3. Schließen Sie ein USB-C-Kabel am darunter liegenden Anschluss des Mikrocontrollers an.

Panel öffnen und USB-C-Anschluss

*Bild 3: Panel öffnen und USB-C-Anschluss für Daten*

> **Wichtiger Hinweis:** Der USB-Anschluss direkt am Mikrocontroller ist ausschließlich zum Flashen der Firmware und zur Übertragung von Konfigurationsparametern vorgesehen. Während des Flashvorgangs darf keine Last am Ausgang geschaltet werden, da dies zu Fehlfunktionen oder zur **Beschädigung des Mikrocontrollers** führen kann.
>
> Es wird daher empfohlen:
> - während der USB-Verbindung keine Last am Ausgang anzuschließen oder
> - den regulären **Power-IN-Eingang** zusätzlich an dieselbe Spannungsversorgung anzuschließen. Dadurch wird sichergestellt, dass der Strom für das Leistungsrelais nicht über den Mikrocontroller fließt und diesen überlastet.

## Schaltausgänge Kanal 1 bis 4 

Die ZapOMat verfügt über vier Relaisausgänge, die intern von den Schaltkontakten (NO/COM/NC) über die Steckverbinderklemmen nach außen geführt werden können. Die Schließerkontakte (NO – Normally Open) sind für die Kanäle 1 bis 3 auf die Klemmen 4, 5 und 6 und für Kanal 4 auf die Klemme 9 verdrahtet.

Die Schaltausgänge sind für eine **maximale Strombelastung von 3 A Dauerlast** ausgelegt. Kurzzeitig können sie auch mit bis zu 5 A belastet werden.

---

## Bedienelemente

Je nach Version verfügt die ZapBox neben dem **LED-Button** über zwei kleine **On-board-Mikrotaster**, die direkt mit dem Mikrocontroller verbunden sind. Alle Funktionen sind sowohl über den LED-Button als auch über die Mikrotaster erreichbar. Zusätzlich hat die ZapBox an der Unterseite des Frontpanels einen Reset-Taster und optional an der Seite ein Schiebeschalter für sonstige Anwendungen.

### Funktionsübersicht - Mikrotaster / LED-Button

| Funktion | Mikrotaster | LED-Button |
|---|---|---|
| Hilfe-Seite anzeigen | 1× HELP drücken | LED-Button mind. 2 Sek. gedrückt halten |
| Nächste Seite / Produktwechsel | 1× NEXT drücken | 1× LED-Button kurz drücken |
| REPORT-Seite anzeigen | 2× HELP drücken | LED-Button 3× schnell hintereinander drücken |
| Config-Modus aufrufen | NEXT mind. 5 Sek. gedrückt halten | 1× kurz drücken, dann mind. 5 Sek. gedrückt halten |

---

## Montagehalterung mit Schnapp-Arretierung

Mit der optionalen Montagehalterung kann die ZapBox leicht montiert werden. 
Die Schnapp-Arretierung kann mit einem flachen Schraubendreher gelöst werden.

Lösen der Montagehalter

*Bild 4: Lösen der Montagehalterung*

> **Hinweis:** Die ZapBox ist auf der Montagehalterung nur aufgeschoben und mit einem Schnappverschluss arretiert. Die Arretierung kann mit einem flachen Schraubendreher gelöst werden. Dazu den Schraubendreher vorsichtig in den Schlitz einschieben, leicht anheben und dabei den oberen Teil der ZapBox in Richtung des Schraubendrehers drücken. Die Verbindung sollte sich lösen und die ZapBox kann von der Montageplatte durch anheben getrennt werden.

---

## Einrichtung und Inbetriebnahme

Die ZapBox wird nach der Fertigung getestet und mit der aktuellen Firmware ausgeliefert - sie ist aber nicht parametriert. Die Software wird aktiv weiterentwickelt, daher ist es empfehlenswert, die ZapBox gleich zu Beginn einmal mit der neuesten Firmware zu bespielen und dann eine Parametrierung durchzuführen. Dafür gibt es einen komfortablen [**Web-Installer**](https://installer.zapbox.space/).

### Schritt 1: Firmware-Update
1. Öffnet das rechte Seitenpanel der Frontblende, wie oben unter "Seitenpanel öffnen" beschrieben.
2. Schließt die ZapBox an dem USB-C-Port mit einem Kabel an und verbindet es mit einem Computer.
3. Öffnet einen Chromium Browser, zum Beispiel Google Chrome, Microsoft Edge, Brave, Vivaldi, Opera oder [Helium](https://helium.computer/).

### Schritt 2: Parametrierung
1. Navigiert im Browser zur Web-Installer-Seite.
2. Folgt den Anweisungen auf der Seite, um die gewünschten Parameter wie `WiFi SSID`, `WiFi Passwort` und `Device Settings String` einzugeben.
3. Speichert die Einstellungen und startet die ZapBox neu.

> **Hinweis:** Während der Einrichtung sollte keine Last an den Ausgängen angeschlossen sein, um Fehlfunktionen oder Schäden am Mikrocontroller zu vermeiden.

Die ZapBox wird nach der Initialisierung den QR-Code des Produkts anzeigen und ist bereit für die erste Zahlung und anschließende Schaltaktion.

### Fehlerdiagnose und -behebung 

Die ZapBox verfügt über eine komfortable Fehleranzeige über das Display. Es gibt vier grundlegende Fehler, die priorisiert sind:

| Prio. | Fehlerart | Abkürzung | Erkennungsmethode | Beschreibung |
|---|---|---|---|---|
| 1 | **NO WIFI** | NW | WiFi-Verbindungsstatus | WiFi-Netzwerk nicht verbunden<br>-> Sind die WiFi-Daten korrekt?<br>-> Ist das WiFi-Signal zu schwach? |
| 2 | **NO INTERNET** | NI | HTTP-Check zu Google | Internetverbindung verloren<br>-> Ist das Internet erreichbar? |
| 3 | **NO SERVER** | NS | TCP-Port 443-Check | LNbits-Server nicht erreichbar<br>-> Ist die Server-Hardware ausgefallen?<br>-> Ist der Geräte-String korrekt? |
| 4 | **NO WEBSOCKET** | NWS | WebSocket-Verbindungsstatus | WebSocket-Protokoll-/Handshake-Fehler<br>-> Ist LNbits ausgefallen?<br>-> Ist der Geräte-String korrekt? |

Die Fehlermeldungen werden auch geloggt und können über den *Report Mode* abgerufen werden:

- Drücken Sie die HELP-Taste zweimal schnell hintereinander, um Fehlerzähler (0-99) für alle vier Fehlertypen mit ihren Auftretenshäufigkeiten anzuzeigen.
- Drücken Sie die LED-Taste dreimal schnell hintereinander (falls eine externe LED-Taste verfügbar ist).

Weitere aktuelle Informationen zu Fehlerbeschreibungen können auf der Web-Installer-Seite in den Kapiteln "Error Detection & Report" und "Troubleshoot" nachgelesen werden. 

---

## NFC-Modul (Option)

Je nach Ausstattung verfügt die ZapBox über ein NFC-Modul, das entweder auf der Oberseite montiert ist oder über den 16-poligen Steckverbinder extern als separates Modul verwendet werden kann.

Die ZapBox unterstützt aktuell folgende Kartentypen:

- **Boltcards** (NTAG424 DNA)
- **LNURL-Withdraw** von NTAG21x (213 / 215 / 216)

Voraussetzung für die Funktion ist die LNbits [ZapBox Extension](https://github.com/AxelHamburch/zapbox_extension). Diese muss vom LNbits-Server unterstützt werden. 

---

## Technische Daten

| Eigenschaft | Wert |
|---|---|
| Versorgungsspannung | 5V DC über USB-C, max. 3A |
| Versorgungsspannung | 6V–36V über DC-Hohlbuchse, max. 3A bei 24V |
| DC-DC Spannungswandler | 6V–36V → 5V, max. 1A Dauerlast, 2A kurzzeitig (2,5A Spitze) |
| Schaltausgänge Relais | Max. 3A Dauerlast (kurzzeitig 5A) |
| Display | 1,9" LCD (T-Display-S3) |
| NFC-Modul | PN532 |
| Temperaturbereich | 0–40 °C |
| Kommunikation | Wi-Fi (ESP32-S3) |
| Zahlungsprotokoll | Bitcoin Lightning Network |

---

## Sicherheitshinweise

- Betreiben Sie das Gerät ausschließlich mit der angegebenen Versorgungsspannung.
- Überschreiten Sie nicht die maximalen Strombelastungen der Ausgänge.
- Führen Sie keine Arbeiten an den Relaiskontakten unter Last durch.
- Das Gerät ist nicht für den Einsatz in feuchten oder nassen Umgebungen geeignet.
- Außerhalb der Reichweite von Kindern aufbewahren.

---

## Weiterführende Links

| Ressource | Link |
|---|---|
| Übersicht aller ZapBox-Modelle | https://zapbox.space/ |
| Web-Installer, Kurzübersicht & Fehlerbehebung | https://installer.zapbox.space/ |
| Detaillierte Dokumentation (Parameter & Funktionen) | https://ereignishorizont.xyz/zapbox/ |
| GitHub-Repository (Software, 3D-Druckdateien, Anleitungen, etc.) | https://github.com/AxelHamburch/ZapBox |
| GitHub-Repository (E-Layouts) | https://github.com/AxelHamburch/ZapBox#electrical-layout |
| ZapBox Extension | https://github.com/AxelHamburch/zapbox_extension |
| LNbits | https://lnbits.com/ |

---

*Änderungen und Irrtümer vorbehalten. Stand: 2026*

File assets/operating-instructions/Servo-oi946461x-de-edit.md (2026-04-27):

# ZapBox Servo – Bedienungsanleitung

**Sprache:** Deutsch | **Version:** oi946461

---

## Inhaltsverzeichnis

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

---

## Einleitung

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

Für den industriellen Einsatz und komfortablen Anschluss kann die Servo, alternativ zum 5V USB-C-Anschluss, mit einem DC-Steckernetzteil betrieben werden. Die Servo kann dafür optional mit einem Weitbereichseingang (DC 6V–36V) über eine Standard 5,5×2,1 mm DC-Buchse angeschlossen werden. Für die intern benötigten 5V ist ein Spannungswandler vorhanden, der selbstregulierend ist. Das erweitert die Anwendungsmöglichkeiten enorm und die Spannungsversorgung für die Ausgänge kann dementsprechend angepasst werden.

Frontansicht

*Bild 1: Frontansicht und Rückansicht*

## Grundausstattung

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

---

## Spannungsversorgung

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

#### Anschlussbeispiele

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

Eine weitere oft Variante ist der von Servomotoren die eine höher Spannung benötigen, z.B. HV-Servos (High Voltage) die Spannungen zwischen 7,4 V und 8,4 V benötigen. Dazu wird die ZapBox an dem DC-Buchseneingang mit z.B. 8 V versorgt und intern die Spannung vor dem Spannungsregler abgegriffen und auf die dafür vorgesehene Klemme 3 und GND verdrahtet. Die externe Brücke zwischen Klemme 1 und Klemme 3 muss dafür entfallen. Damit sind die Schaltausgänge 1 bis 3 mit der Spannung 8 V gespeist und können die Motoren antreiben. Die Strombelastung sollte nicht mehr als 3 Ampere betragen, da diese aktuell das Limit für die interen Verdrahtung ist. Der Schaltausgang 4 kann mit einer Brücke zwischen 1 und 8 mit 5 V gespeist werden. Damit kann der Kanal 4 dann z.B. für ein LED-Licht als Ambientlicht für den Hintergrund geschaltet werden.

#### Zusatzinformation

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

### Spannungseingang USB-C Buchse (5V) 

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

### Spannungseingang DC-Hohlsteckerbuchse (6 V–36 V)

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

## Externe Anschlüsse – 16-poliger Steckverbinder

Die ZapBox verfügt über einen abnehmbaren 16-poligen Steckverbinder.

**Klemmenbelegung in der Übersicht:**
| Klemme | Funktion | Verwendung | Hinweis |
|---|---|---|---|
| 1 | 5 V | Ausgang | Spannungsversorgung 5 V |
| 2 | GND | Ausgang | Masse / 0 V |
| 3 | Versorgung Kanal 1-3 | Eingang / Ausgang | 5 V oder 6 V–36 V |
| 4 | CH1 Schaltausgang Kanal 1 (GPIO Pin 12) | Ausgang | Ansteuerung Verbraucher (NO – Normally Open) |
| 5 | CH2 Servo Steuersignal 1 (GPIO Pin 13) | Ausgang | Ansteuerung Servomotor (pulsierend, 3,3 V) |
| 6 | CH3 Servo Steuersignal 2 (GPIO Pin 11) | Ausgang | Ansteuerung Servomotor (pulsierend, 3,3 V) |
| 7 | GND | Ausgang | Masse / 0 V  |
| 8 | Versorgung Kanal 4 | Eingang / Ausgang | 5 V oder 6 V–36 V |
| 9 | CH4 Schaltausgang Relais Kanal 4 (GPIO Pin 11) | Ausgang | Ansteuerung Verbraucher (NO – Normally Open) |
| 10 | GND| Ausgang | Masse / 0 V |
| 11 | Sensor (GPIO Pin 2) | Eingang | Für z.B. eine Lichtschranke (NPN) |
| 12 | 5 V | Ausgang | 5 V für Sensor und NFC-Modul |
| 13 | GND | Ausgang | Masse für Sensor und NFC-Modul |
| 14 | NFC IRQ (GPIO Pin 1) | Schnittstelle | Externes NFC-Modul |
| 15 | I2C SCL (GPIO Pin 17) | Schnittstelle | Externes NFC-Modul |
| 16 | I2C SDA (GPIO Pin 18) | Schnittstelle | Externes NFC-Modul |

Draufsicht

*Bild 2: Reihenfolge Klemmenbelegung Steckverbinder, von rechts nach links*

**Hinweis zur Belegung:** 

Die ZapBox Servo verfügt über 4 Ausgänge Kanal 1 bis Kanal 4. Kanal 1 und 4 sind fest auf Relais verdrahtet. Kanal 2 und 3 gehen direkt zum Ausgang sind vorwiegend zur Servoansteuerung gedacht. Auf den Ausgangsklemmen 5 und 6 liegt das Steuersignal der GPIO Pins 13 und 10 an. 

**Hinweis Spannungsverteilung mit Brücken:** 

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

Jumper

*Bild 3: Auszug E-Layout - Klemmen die gebrückt sind*

**Hinweis zu den Relaiskontakten:** 

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

**Hinweis zu DC-Buchse (6 V–36 V für Klemmen 3 & 8):** 

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

## USB-C-Anschluss

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

*Bild 4: Panel öffnen und USB-C-Anschluss für Daten*

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

## Schaltausgänge Kanal 1 bis 4 

Die Servo verfügt über vier Relaisausgänge, die intern von den Schaltkontakten (NO/COM/NC) über die Steckverbinderklemmen nach außen geführt werden können. Die Schließerkontakte (NO – Normally Open) sind für die Kanäle 1 bis 3 auf die Klemmen 4, 5 und 6 und für Kanal 4 auf die Klemme 9 verdrahtet.

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

---

## Bedienelemente

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

### Funktionsübersicht - Mikrotaster / LED-Button

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

---

## Montagehalterung mit Schnapp-Arretierung

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

Lösen der Montagehalter

*Bild 5: Lösen der Montagehalterung*

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

---

## Einrichtung und Inbetriebnahme

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

### Fehlerdiagnose und -behebung 

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

Die Fehlermeldungen werden auch geloggt und können über den *Report Mode* abgerufen werden:

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

---

## NFC-Modul (Option)

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

Die ZapBox unterstützt aktuell folgende Kartentypen:

- **Boltcards** (NTAG424 DNA)
- **LNURL-Withdraw** von NTAG21x (213 / 215 / 216)

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

---

## Technische Daten

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

---

## Sicherheitshinweise

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

---

## Weiterführende Links

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

---

*Änderungen und Irrtümer vorbehalten. Stand: 2026*

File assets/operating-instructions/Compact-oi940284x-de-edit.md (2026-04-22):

# ZapBox Compact – Bedienungsanleitung

**Sprache:** Deutsch | **Version:** oi940284

---

## Inhaltsverzeichnis

1. [Einleitung](#einleitung)
2. [Ansichten](#ansichten)
3. [Anschlüsse](#anschlüsse)
4. [Bedienelemente](#bedienelemente)
5. [Einrichtung und Inbetriebnahme](#einrichtung-und-inbetriebnahme)
6. [Option: NFC-Modul](#option-nfc-modul)
7. [Technische Daten](#technische-daten)
8. [Sicherheitshinweise](#sicherheitshinweise)
9. [Weiterführende Links](#weiterführende-links)

---

## Einleitung

Die **ZapBox Compact** ist ein elektronischer Schalter für Bitcoin-Lightning-Zahlungen. Mit einer Zahlung über das Lightning-Netzwerk lässt sich ein Ausgang schalten – ideal für Automaten, Präsentationen, Eventsteuerung und viele weitere Anwendungen.

### Grundausstattung

| Komponente | Beschreibung |
|---|---|
| Mikrocontroller | T-Display-S3 mit 1,9" LCD-Display |
| Frontpanel | Wahlweise mit 35° oder 90° Display Front (90° auch zum Einbau erhältlich) |
| Eingang | USB-C (Power IN) |
| Ausgang | USB-A Buchse |
| Bedienelement | Zwei On-board-Mikrotaster |
| Schalter 1 | 3-poliger Schiebeschalter (AUTO / OFF / ON) |
| Schalter 2 | 2-poliger Schiebeschalter (Invert Output) |
| Option BTC-Ticker | Aktivierbar über den Web Installer |
| Option NFC-Modul | Für Bolt Cards (NTAG424 DNA) und Standard NTAG213/215/216 (mit LNURL-withdraw) |

---

## Ansichten

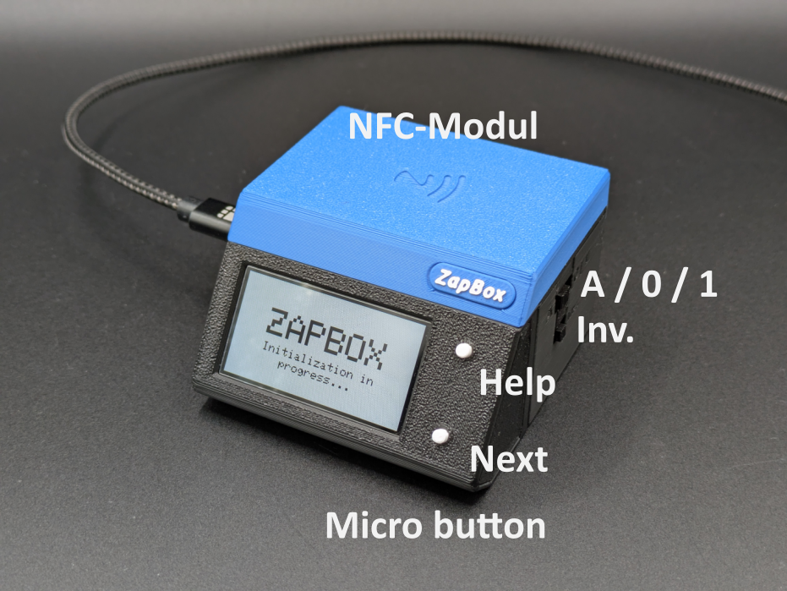
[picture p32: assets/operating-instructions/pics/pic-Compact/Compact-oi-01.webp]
Frontansicht


*Bild 1: Frontansicht*

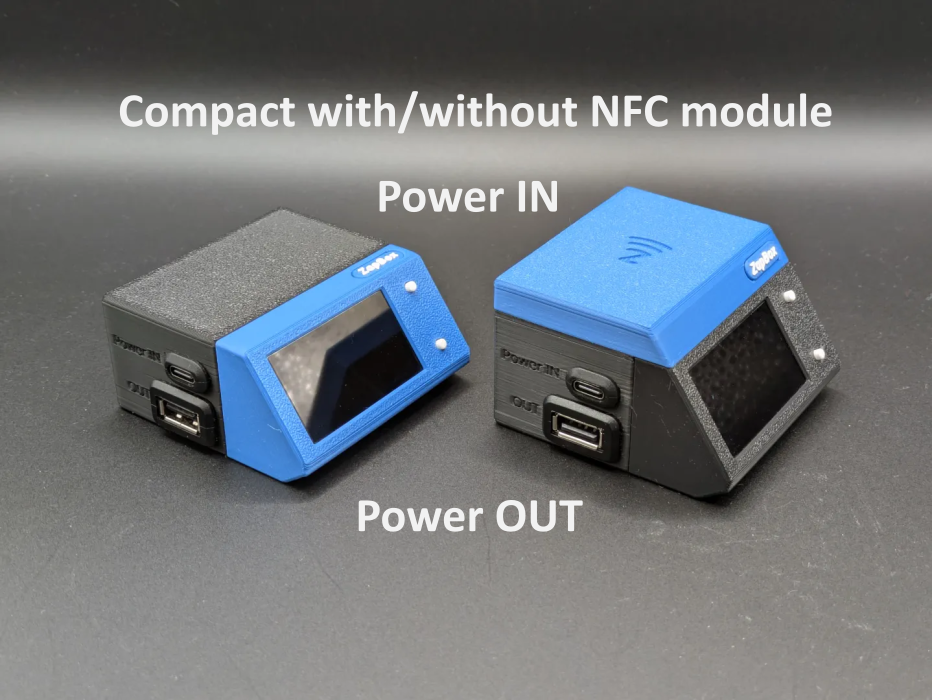
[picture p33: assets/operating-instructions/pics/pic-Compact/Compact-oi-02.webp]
Rückansicht


*Bild 2: Rückansicht*

---

## Anschlüsse

### Eingang - USB-C Buchse zur Spannungsversorgung (5V)

Versorgen Sie das Gerät über den Anschluss **Power IN** mit einem USB-C-Kabel mit **5 V DC (max. 5 A)**.

> **Hinweis:** Der USB-Power-Anschluss unterstützt keine automatische USB-C-Leistungsanforderung (kein USB-C Power Delivery). Einige USB-C-Ladegeräte oder Powermodule erkennen die ZapBox daher nicht als Verbraucher und liefern keinen Strom. Verwenden Sie in diesem Fall einen **USB-A-Ausgang** der Spannungsversorgung oder eine alternative 5-V-Stromquelle. Die maximale Stromstärke darf 3 A nicht überschreiten.

---

### Eingang - USB-C Buchse am Mikrocontroller (Datenzugang, hinter rechtem Seitenpanel)

Um Daten vom Gerät zu lesen oder zu übertragen, verbinden Sie die ZapBox mit einem Computer oder Laptop:

1. An der **rechten Seite der Frontblende** befindet sich eine kleine, verdeckte Klappe.
2. Öffnen Sie die Klappe, indem Sie von unten mit einem **schmalen Schraubendreher** die Klappe nach rechts wegschieben.
3. Schließen Sie ein USB-C-Kabel am darunter liegenden Anschluss des Mikrocontrollers an.

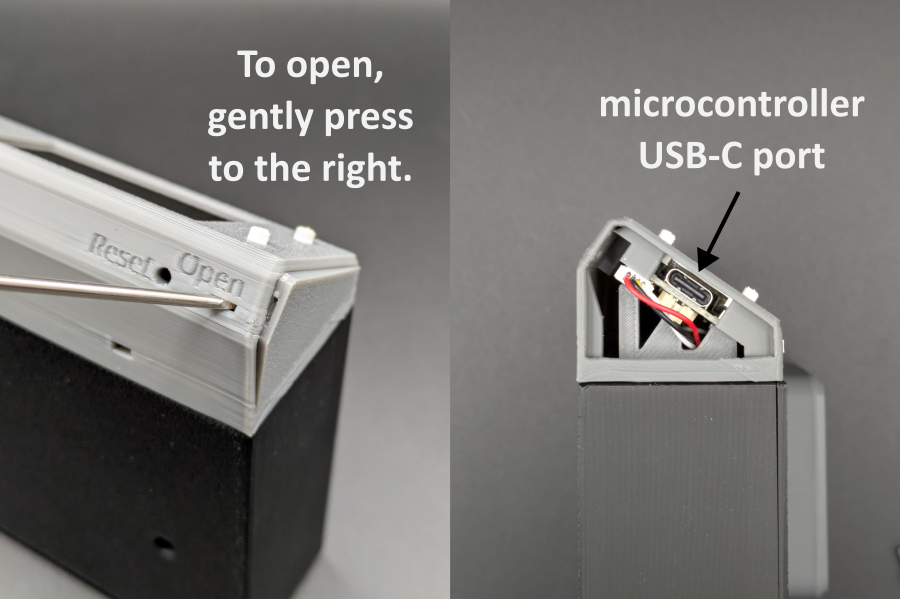
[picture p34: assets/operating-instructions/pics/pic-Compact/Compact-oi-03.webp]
Panel öffnen und USB-C-Anschluss


*Bild: Panel öffnen und USB-C-Anschluss für Daten*

> **Wichtiger Hinweis:** Der USB-Anschluss direkt am Mikrocontroller ist ausschließlich zum Flashen der Firmware und zur Übertragung von Konfigurationsparametern vorgesehen. Während des Flashvorgangs darf keine Last am Ausgang angeschlossen oder geschaltet werden, da dies zu Fehlfunktionen oder zur **Beschädigung des Mikrocontrollers** führen kann.
>
> Es wird daher empfohlen:
> - während der USB-Verbindung keine Last am Ausgang anzuschließen oder
> - den regulären **Power-IN-Eingang** zusätzlich an dieselbe Spannungsversorgung anzuschließen. Dadurch wird sichergestellt, dass der Strom für das Leistungsrelais nicht über den Mikrocontroller fließt und diesen überlastet.

---

### Ausgang - USB-A-Buchse (geschaltete 5V Spannung)

Die USB-Buchse wird über einen Relais-Schaltkontakt geschaltet. Die **Gesamtbelastung** der Buchsen sollte **3 A nicht überschreiten**.

---

## Bedienelemente

Die ZapBox verfügt über zwei kleine **On-board-Mikrotaster**, die direkt mit dem Mikrocontroller verbunden sind. Alle Funktionen sind über die Mikrotaster erreichbar. Zusätzlich hat die ZapBox an der Unterseite des Frontpanels einen Reset Taster und an der Seite zwei Schiebeschalter.

### Funktionsübersicht - Mikrotaster

| Funktion | Mikrotaster |
|---|---|
| Hilfe-Seite anzeigen | 1× HELP drücken | 
| Nächste Seite / Produktwechsel | 1× NEXT drücken |
| REPORT-Seite anzeigen | 2× HELP drücken | 
| Config-Modus aufrufen | NEXT mind. 5 Sek. gedrückt halten |

### Funktionsübersicht - Schiebeschalter

Die ZapBox Compact verfügt über zwei Schiebeschalter.

#### Schalter 1 – Dreifach-Schiebeschalter (AUTO / OFF / ON)

| Stellung | Funktion |
|---|---|
| **A** (AUTO) | Automatikbetrieb – Normalbetrieb |
| **0** (OFF) | Spannungsversorgung unterbrochen – Ausgang AUS |
| **1** (ON) | Ausgang dauerhaft EIN (Bei Schalter 2 - Inverse = AUS) |

#### Schalter 2 – Zweifach-Schiebeschalter (standard / invertiert)

| Stellung | Funktion |
|---|---|
| **Std.** (Standard) | Der Ausgang ist im Ruhezustand spannungslos (0 V). Nach dem Schaltvorgang liegt 5 V an den USB-Buchsen an. |
| **Inv.** (Inverse) | Der Ausgang liegt im Ruhezustand auf 5 V. Nach dem Schaltvorgang wechselt der Ausgang auf 0 V (inverses Schalten). |

> **Hinweis:** Befindet sich der Zweifach-Schalter auf **Inv.** und der Dreifach-Schalter auf **Stellung 1**, ist der Ausgang – anders als im Normalbetrieb – **AUS** statt EIN.

---

## Einrichtung und Inbetriebnahme

Die ZapBox wird nach der Fertigung getestet und mit der aktuellen Firmware ausgeliefert - sie ist aber nicht parametriert. Die Software wird aktiv weiterentwickelt, daher ist es empfehlenswert, die ZapBox gleich zu Beginn einmal mit der neuesten Firmware zu bespielen und dann eine Parametrierung durchzuführen. Dafür gibt es einen komfortablen [**Web-Installer**](https://installer.zapbox.space/).

### Schritt 1: Firmware-Update
1. Öffnet das rechte Seitenpanel der Frontblende, wie oben unter "Seitenpanel öffnen" beschrieben.
2. Schließt die ZapBox an dem USB-C-Port mit einem Kabel an und verbindet es mit einem Computer.
3. Öffnet einen Chromium Browser, zum Beispiel Google Chrome, Microsoft Edge, Brave, Vivaldi, Opera oder [Helium](https://helium.computer/).

### Schritt 2: Parametrierung
1. Navigiert im Browser zur Web-Installer-Seite.
2. Folgt den Anweisungen auf der Seite, um die gewünschten Parameter wie `WiFi SSID`, `WiFi Passwort` und `Device Settings String` einzugeben.
3. Speichert die Einstellungen und startet die ZapBox neu.

> **Hinweis:** Während der Einrichtung sollte keine Last an den Ausgängen angeschlossen sein, um Fehlfunktionen oder Schäden am Mikrocontroller zu vermeiden.

Die ZapBox wird nach der Initialisierung den QR-Code des Produkts anzeigen und ist bereit für die erste Zahlung und anschließende Schaltaktion.

### Fehlerdiagnose und -behebung 

Die ZapBox verfügt über eine komfortable Fehleranzeige über das Display. Es gibt vier grundlegende Fehler, die priorisiert sind:

| Prio. | Fehlerart | Abkürzung | Erkennungsmethode | Beschreibung |
|---|---|---|---|---|
| 1 | **NO WIFI** | NW | WiFi-Verbindungsstatus | WiFi-Netzwerk nicht verbunden<br>-> Sind die WiFi-Daten korrekt?<br>-> Ist das WiFi-Signal zu schwach? |
| 2 | **NO INTERNET** | NI | HTTP-Check zu Google | Internetverbindung verloren<br>-> Ist das Internet erreichbar? |
| 3 | **NO SERVER** | NS | TCP-Port 443-Check | LNbits-Server nicht erreichbar<br>-> Ist die Server-Hardware ausgefallen?<br>-> Ist der Geräte-String korrekt? |
| 4 | **NO WEBSOCKET** | NWS | WebSocket-Verbindungsstatus | WebSocket-Protokoll-/Handshake-Fehler<br>-> Ist LNbits ausgefallen?<br>-> Ist der Geräte-String korrekt? |

Die Fehlermeldungen werden auch geloggt und können über den *Report Mode* abgerufen werden:

- Drücken Sie die HELP-Taste zweimal schnell hintereinander, um Fehlerzähler (0-99) für alle vier Fehlertypen mit ihren Auftretenshäufigkeiten anzuzeigen.
- Drücken Sie die LED-Taste dreimal schnell hintereinander (falls eine externe LED-Taste verfügbar ist).

Weitere aktuelle Informationen zu Fehlerbeschreibungen können auf der Web-Installer-Seite in den Kapiteln "Error Detection & Report" und "Troubleshoot" nachgelesen werden. 

---

## Option: NFC-Modul

Je nach Ausstattung ist auf der **Oberseite der ZapBox** ein NFC-Modul verbaut. Alternativ ist das Modul auch separat erhältlich. Die ZapBox unterstützt aktuell folgende Kartentypen:

- **Boltcards** (NTAG424)
- **LNURL-Withdraw** von NTAG21x (213 / 215 / 216)

Voraussetzung für die Funktion ist die LNbits [ZapBox Extension](https://github.com/AxelHamburch/zapbox_extension). Sie muss von dem LNbits Server unterstützt werden. 

---

## Technische Daten

| Eigenschaft | Wert |
|---|---|
| Versorgungsspannung | 5 V DC über USB-C |
| Maximaler Eingangsstrom | 5,0 A |
| Ausgangsleistung | max. 3,0 A (empfohlen) |
| Temperaturbereich | 0–40 °C |
| Display | 1,9" LCD (T-Display-S3) |
| Kommunikation | Wi-Fi (ESP32-S3) |
| Zahlungsprotokoll | Bitcoin Lightning Network |

---

## Sicherheitshinweise

- Betreiben Sie das Gerät ausschließlich mit der angegebenen Versorgungsspannung.
- Überschreiten Sie nicht die maximalen Strombelastungen der Ausgänge.
- Führen Sie keine Arbeiten an den Relaiskontakten unter Last durch.
- Das Gerät ist nicht für den Einsatz in feuchten oder nassen Umgebungen geeignet.
- Außerhalb der Reichweite von Kindern aufbewahren.

---

## Weiterführende Links

| Ressource | Link |
|---|---|
| Übersicht aller ZapBox-Modelle | https://zapbox.space/ |
| Web-Installer, Kurzübersicht & Fehlerbehebung | https://installer.zapbox.space/ |
| Detaillierte Dokumentation (Parameter & Funktionen) | https://ereignishorizont.xyz/zapbox/ |
| GitHub-Repository (Software, E-Layouts, 3D-Druckdateien, Bedienungsanleitungen) | https://github.com/AxelHamburch/ZapBox |
| ZapBox Extension | https://github.com/AxelHamburch/zapbox_extension |
| LNbits | https://lnbits.com/ |

---

*Änderungen und Irrtümer vorbehalten. Stand: 2026*

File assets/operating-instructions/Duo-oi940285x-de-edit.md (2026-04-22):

# ZapBox Duo – Bedienungsanleitung

**Sprache:** Deutsch | **Version:** oi940285

---

## Inhaltsverzeichnis

1. [Einleitung](#einleitung)
2. [Ansichten](#ansichten)
3. [Anschlüsse](#anschlüsse)
4. [Bedienelemente](#bedienelemente)
5. [Einrichtung und Inbetriebnahme](#einrichtung-und-inbetriebnahme)
6. [NFC-Modul (optional)](#nfc-modul-optional)
7. [Technische Daten](#technische-daten)
8. [Sicherheitshinweise](#sicherheitshinweise)
9. [Weiterführende Links](#weiterführende-links)

---

## Einleitung

Die **ZapBox Duo** ist ein elektronischer Schalter für Bitcoin-Lightning-Zahlungen. Mit einer Zahlung über das Lightning-Netzwerk lassen sich zwei unabhängige Ausgänge schalten – ideal für Automaten, Präsentationen, Eventsteuerung und viele weitere Anwendungen.

### Grundausstattung

| Komponente | Beschreibung |
|---|---|
| Mikrocontroller | T-Display-S3 mit 1,9" LCD-Display |
| Frontpanel | Wahlweise mit 35° oder 90° Display Front (90° auch zum Einbau erhältlich) |
| Eingang | USB-C (Power IN) |
| Ausgang Kanal 1 (CH1) | 30-A-Leistungsrelais mit externen Klemmen |
| Ausgang Kanal 2 (CH2) | Doppelbuchse mit USB-A und USB-C |
| Bedienelement | LED-Button (volle ZapBox-Funktionalität) |
| Schalter 1 | 3-poliger Schiebeschalter (AUTO / OFF / ON) |
| Schalter 2 | 2-poliger Schiebeschalter (Invert Output) |
| Option BTC-Ticker | Aktivierbar über den Web Installer |
| Option Boardtaster | Zwei On-board-Mikrotaster |
| Option NFC-Modul | Für Bolt Cards (NTAG424 DNA) und Standard NTAG213/215/216 (mit LNURL-withdraw) |

---

## Ansichten

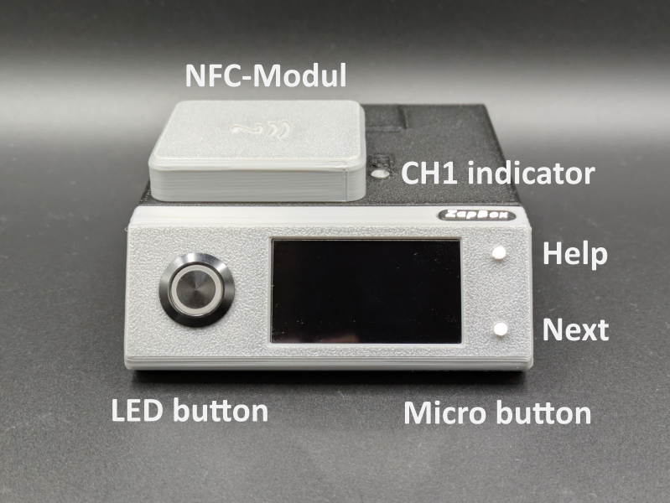
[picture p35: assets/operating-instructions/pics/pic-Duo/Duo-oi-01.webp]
Frontansicht


*Bild 1: Frontansicht*

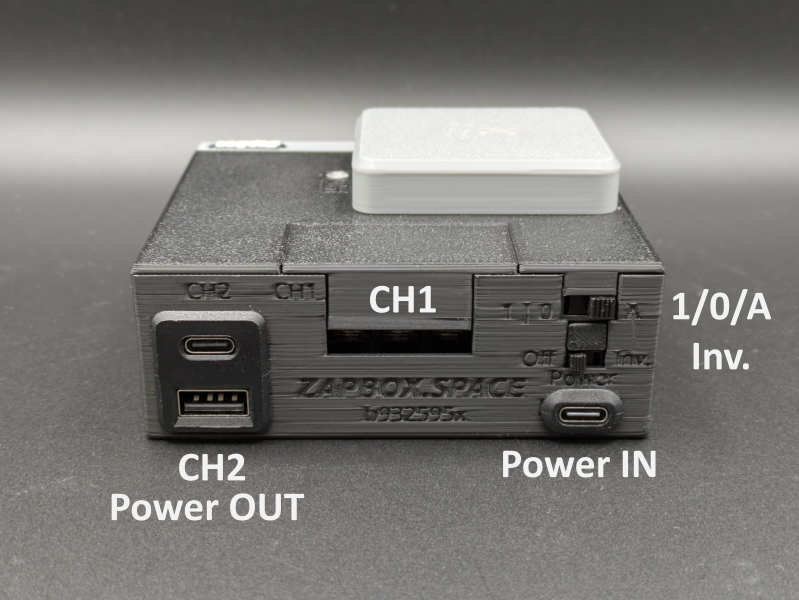
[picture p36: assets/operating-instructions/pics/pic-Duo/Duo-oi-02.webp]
Rückansicht


*Bild 2: Rückansicht*

---

## Anschlüsse

### Eingang - USB-C Buchse zur Spannungsversorgung (5V)

Versorgen Sie das Gerät über den Anschluss **Power IN** mit einem USB-C-Kabel mit **5 V DC (max. 5 A)**.

> **Hinweis:** Der USB-Power-Anschluss unterstützt keine automatische USB-C-Leistungsanforderung (kein USB-C Power Delivery). Einige USB-C-Ladegeräte oder Powermodule erkennen die ZapBox daher nicht als Verbraucher und liefern keinen Strom. Verwenden Sie in diesem Fall einen **USB-A-Ausgang** der Spannungsversorgung oder eine alternative 5-V-Stromquelle. Die maximale Stromstärke darf 3 A nicht überschreiten.

---

### Eingang - USB-C Buchse am Mikrocontroller (Datenzugang, hinter rechtem Seitenpanel)

Um Daten vom Gerät zu lesen oder zu übertragen, verbinden Sie die ZapBox mit einem Computer oder Laptop:

1. An der **rechten Seite der Frontblende** befindet sich eine kleine, verdeckte Klappe.
2. Öffnen Sie die Klappe, indem Sie von unten mit einem **schmalen Schraubendreher** die Klappe nach rechts wegschieben.
3. Schließen Sie ein USB-C-Kabel am darunter liegenden Anschluss des Mikrocontrollers an.

Panel öffnen und USB-C-Anschluss

*Bild: Panel öffnen und USB-C-Anschluss für Daten*

> **Wichtiger Hinweis:** Der USB-Anschluss direkt am Mikrocontroller ist ausschließlich zum Flashen der Firmware und zur Übertragung von Konfigurationsparametern vorgesehen. Während des Flashvorgangs darf keine Last am Ausgang angeschlossen oder geschaltet werden, da dies zu Fehlfunktionen oder zur **Beschädigung des Mikrocontrollers** führen kann.
>
> Es wird daher empfohlen:
> - während der USB-Verbindung keine Last am Ausgang anzuschließen oder
> - den regulären **Power-IN-Eingang** zusätzlich an dieselbe Spannungsversorgung anzuschließen. Dadurch wird sichergestellt, dass der Strom für das Leistungsrelais nicht über den Mikrocontroller fließt und diesen überlastet.

### Ausgang

#### Kanal 1 (CH1) – Leistungsrelais 30 A

Das Leistungsrelais auf Kanal 1 führt die Kontakte **COM / NO / NC** nach außen. Diese sind werkseitig mit einer **Schutzkappe** abgedeckt.

- **Kappe abnehmen:** Einfach nach oben abziehen.
- **Kappe aufsetzen:** Zunächst die lange Seite auflegen, anschließend den kurzen Winkel nach unten drücken, bis die Kappe einrastet.

Die Kontakte des Leistungsrelais sind für eine **maximale Strombelastung von 30 A** ausgelegt.

Auf der **Oberseite der ZapBox** befindet sich eine kleine transparente Öffnung. Eine LED dahinter zeigt den **EIN-Status des Leistungsrelais** an.

#### Kanal 2 (CH2) – Doppel-USB-Buchse (USB-A / USB-C)

Die Doppel-USB-Buchse wird über einen Relais-Schaltkontakt (CH2) geschaltet. Die **Gesamtbelastung** der Buchsen sollte **3 A nicht überschreiten**.

---

## Bedienelemente

Je nach Version verfügt die ZapBox neben dem **LED-Button** über zwei kleine **On-board-Mikrotaster**, die direkt mit dem Mikrocontroller verbunden sind. Alle Funktionen sind sowohl über den LED-Button als auch über die Mikrotaster erreichbar. Zusätzlich hat die ZapBox an der Unterseite des Frontpanels einen Reset-Taster und an der Seite zwei Schiebeschalter.

### Funktionsübersicht - Mikrotaster / LED-Button

| Funktion | Mikrotaster | LED-Button |
|---|---|---|
| Hilfe-Seite anzeigen | 1× HELP drücken | LED-Button mind. 2 Sek. gedrückt halten |
| Nächste Seite / Produktwechsel | 1× NEXT drücken | 1× LED-Button kurz drücken |
| REPORT-Seite anzeigen | 2× HELP drücken | LED-Button 3× schnell hintereinander drücken |
| Config-Modus aufrufen | NEXT mind. 5 Sek. gedrückt halten | 1× kurz drücken, dann mind. 5 Sek. gedrückt halten |

### Funktionsübersicht - Schiebeschalter

Die ZapBox Duo verfügt über zwei Schiebeschalter.

#### Schalter 1 – Dreifach-Schiebeschalter (AUTO / OFF / ON)

| Stellung | Funktion |
|---|---|
| **A** (AUTO) | Automatikbetrieb – Normalbetrieb |
| **0** (OFF) | Spannungsversorgung unterbrochen – Ausgang AUS |
| **1** (ON) | Ausgang CH2 (Doppel-USB A/C) dauerhaft EIN (Bei Schalter 2 - Inverse = AUS) |

#### Schalter 2 – Zweifach-Schiebeschalter (standard / invertiert)

| Stellung | Funktion |
|---|---|
| **Std.** (Standard) | Der Ausgang ist im Ruhezustand spannungslos (0 V). Nach dem Schaltvorgang liegt 5 V an den USB-Buchsen an. |
| **Inv.** (Inverse) | Der Ausgang liegt im Ruhezustand auf 5 V. Nach dem Schaltvorgang wechselt der Ausgang auf 0 V (inverses Schalten). |

> **Hinweis:** Befindet sich der Zweifach-Schalter auf **Inv.** und der Dreifach-Schalter auf **Stellung 1**, ist der Ausgang – anders als im Normalbetrieb – **AUS** statt EIN.

---

## Einrichtung und Inbetriebnahme

Die ZapBox wird nach der Fertigung getestet und mit der aktuellen Firmware ausgeliefert - sie ist aber nicht parametriert. Die Software wird aktiv weiterentwickelt, daher ist es empfehlenswert, die ZapBox gleich zu Beginn einmal mit der neuesten Firmware zu bespielen und dann eine Parametrierung durchzuführen. Dafür gibt es einen komfortablen [**Web-Installer**](https://installer.zapbox.space/).

### Schritt 1: Firmware-Update
1. Öffnet das rechte Seitenpanel der Frontblende, wie oben unter "Seitenpanel öffnen" beschrieben.
2. Schließt die ZapBox an dem USB-C-Port mit einem Kabel an und verbindet es mit einem Computer.
3. Öffnet einen Chromium Browser, zum Beispiel Google Chrome, Microsoft Edge, Brave, Vivaldi, Opera oder [Helium](https://helium.computer/).

### Schritt 2: Parametrierung
1. Navigiert im Browser zur Web-Installer-Seite.
2. Folgt den Anweisungen auf der Seite, um die gewünschten Parameter wie `WiFi SSID`, `WiFi Passwort` und `Device Settings String` einzugeben.
3. Speichert die Einstellungen und startet die ZapBox neu.

> **Hinweis:** Während der Einrichtung sollte keine Last an den Ausgängen angeschlossen sein, um Fehlfunktionen oder Schäden am Mikrocontroller zu vermeiden.

Die ZapBox wird nach der Initialisierung den QR-Code des Produkts anzeigen und ist bereit für die erste Zahlung und anschließende Schaltaktion.

### Fehlerdiagnose und -behebung 

Die ZapBox verfügt über eine komfortable Fehleranzeige über das Display. Es gibt vier grundlegende Fehler, die priorisiert sind:

| Prio. | Fehlerart | Abkürzung | Erkennungsmethode | Beschreibung |
|---|---|---|---|---|
| 1 | **NO WIFI** | NW | WiFi-Verbindungsstatus | WiFi-Netzwerk nicht verbunden<br>-> Sind die WiFi-Daten korrekt?<br>-> Ist das WiFi-Signal zu schwach? |
| 2 | **NO INTERNET** | NI | HTTP-Check zu Google | Internetverbindung verloren<br>-> Ist das Internet erreichbar? |
| 3 | **NO SERVER** | NS | TCP-Port 443-Check | LNbits-Server nicht erreichbar<br>-> Ist die Server-Hardware ausgefallen?<br>-> Ist der Geräte-String korrekt? |
| 4 | **NO WEBSOCKET** | NWS | WebSocket-Verbindungsstatus | WebSocket-Protokoll-/Handshake-Fehler<br>-> Ist LNbits ausgefallen?<br>-> Ist der Geräte-String korrekt? |

Die Fehlermeldungen werden auch geloggt und können über den *Report Mode* abgerufen werden:

- Drücken Sie die HELP-Taste zweimal schnell hintereinander, um Fehlerzähler (0-99) für alle vier Fehlertypen mit ihren Auftretenshäufigkeiten anzuzeigen.
- Drücken Sie die LED-Taste dreimal schnell hintereinander (falls eine externe LED-Taste verfügbar ist).

Weitere aktuelle Informationen zu Fehlerbeschreibungen können auf der Web-Installer-Seite in den Kapiteln "Error Detection & Report" und "Troubleshoot" nachgelesen werden. 

---

## NFC-Modul (optional)

Je nach Ausstattung ist auf der **Oberseite der ZapBox** ein NFC-Modul verbaut. Es unterstützt folgende Kartentypen:

- **Boltcards** (NTAG424)
- **LNURL-Withdraw** von NTAG21x (213 / 215 / 216)

Voraussetzung für die Funktion ist die LNbits [ZapBox Extension](https://github.com/AxelHamburch/zapbox_extension). Sie muss von dem LNbits Server unterstützt werden. 

---

## Technische Daten

| Eigenschaft | Wert |
|---|---|
| Versorgungsspannung | 5 V DC über USB-C |
| Maximaler Eingangsstrom | 5,0 A |
| CH1 Schaltleistung | max. 30 A |
| CH2 Ausgangsleistung | max. 3,0 A (empfohlen/gesamt) |
| Temperaturbereich | 0–40 °C |
| Display | 1,9" LCD (T-Display-S3) |
| Kommunikation | Wi-Fi (ESP32-S3) |
| Zahlungsprotokoll | Bitcoin Lightning Network |

---

## Sicherheitshinweise

- Betreiben Sie das Gerät ausschließlich mit der angegebenen Versorgungsspannung.
- Überschreiten Sie nicht die maximalen Strombelastungen der Ausgänge.
- Führen Sie keine Arbeiten an den Relaiskontakten unter Last durch.
- Das Gerät ist nicht für den Einsatz in feuchten oder nassen Umgebungen geeignet.
- Außerhalb der Reichweite von Kindern aufbewahren.

---

## Weiterführende Links

| Ressource | Link |
|---|---|
| Übersicht aller ZapBox-Modelle | https://zapbox.space/ |
| Web-Installer, Kurzübersicht & Fehlerbehebung | https://installer.zapbox.space/ |
| Detaillierte Dokumentation (Parameter & Funktionen) | https://ereignishorizont.xyz/zapbox/ |
| GitHub-Repository (Software, E-Layouts, 3D-Druckdateien, Bedienungsanleitungen) | https://github.com/AxelHamburch/ZapBox |
| ZapBox Extension | https://github.com/AxelHamburch/zapbox_extension |
| LNbits | https://lnbits.com/ |

---

*Änderungen und Irrtümer vorbehalten. Stand: 2026*

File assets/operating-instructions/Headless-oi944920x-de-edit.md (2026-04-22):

# ZapBox Headless – Bedienungsanleitung

**Sprache:** Deutsch | **Version:** oi944920

---

## Inhaltsverzeichnis

1. [Einleitung](#einleitung)
2. [Ansichten](#ansichten)
3. [Anschlüsse](#anschlüsse)
4. [Bedienelemente](#bedienelemente)
5. [Einrichtung und Inbetriebnahme](#einrichtung-und-inbetriebnahme)
6. [Option: NFC-Modul](#option-nfc-modul)
7. [Technische Daten](#technische-daten)
8. [Sicherheitshinweise](#sicherheitshinweise)
9. [Weiterführende Links](#weiterführende-links)

---

## Einleitung

Die **ZapBox Headless** ist ein elektronischer Schalter für Bitcoin-Lightning-Zahlungen ohne Display. Mit einer Zahlung über das Lightning-Netzwerk lässt sich ein Ausgang schalten – ideal für eingebettete Anwendungen, verdeckte Installationen, Maschinenbau und überall dort, wo kein Display benötigt wird.

Der Betriebszustand wird ausschließlich über eine **Status-LED** angezeigt. Eine zweite **Action-LED** zeigt die Schaltfunktion an.

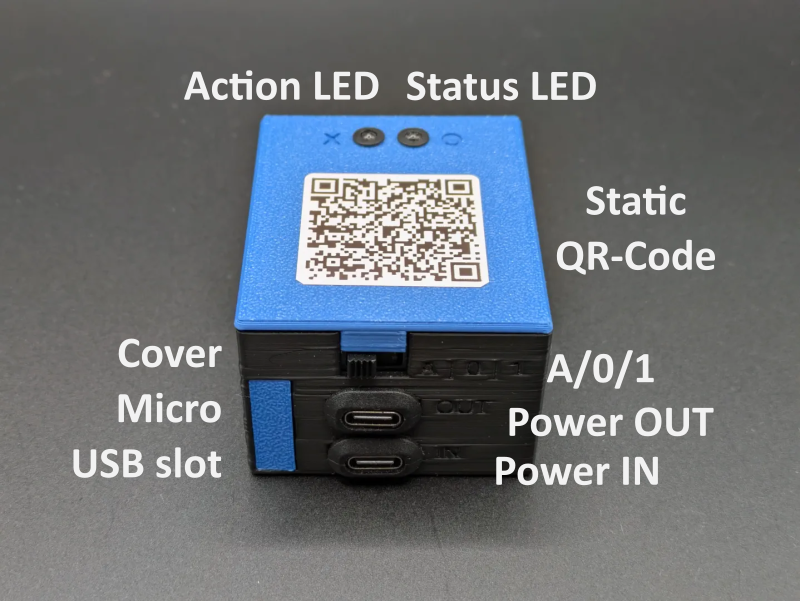
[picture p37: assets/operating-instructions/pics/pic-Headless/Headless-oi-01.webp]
Frontansicht-Draufsicht


*Bild 1: Frontansicht / Draufsicht*

### Grundausstattung

| Komponente | Beschreibung |
|---|---|
| Mikrocontroller | ESP32 Dev Module (kein Display) |
| Eingang | USB-C (Power IN) |
| Ausgang | USB-C (Power OUT) |
| Statusanzeige | Status-LED mit Blinkmustern und Action-LED als Rückmeldung |
| Bedienelement | Mikrotaster für BOOT (Config-Modus) und Reset |
| Schalter | 3-poliger Schiebeschalter (AUTO / OFF / ON) |
| Option NFC-Modul | Für Bolt Cards (NTAG424 DNA) und Standard NTAG213/215/216 (mit LNURL-withdraw) |

---

## Anschlüsse

### Eingang - USB-C Buchse zur Spannungsversorgung (5V)

Versorgen Sie das Gerät über den Anschluss **Power IN** mit einem USB-C-Kabel mit **5 V DC (max. 5 A)**.

> **Hinweis:** Der USB-Power-Anschluss unterstützt keine automatische USB-C-Leistungsanforderung (kein USB-C Power Delivery). Einige USB-C-Ladegeräte oder Powermodule erkennen die ZapBox daher nicht als Verbraucher und liefern keinen Strom. Verwenden Sie in diesem Fall einen **USB-A-Ausgang** der Spannungsversorgung oder eine alternative 5-V-Stromquelle. Die maximale Stromstärke darf 3 A nicht überschreiten.

---

### Eingang - Micro-USB Buchse am Mikrocontroller (Datenzugang, vorne)

Um Daten vom Gerät zu lesen oder zu übertragen, verbinden Sie die ZapBox mit einem Computer oder Laptop:

1. An der **Vorderseite links** befindet sich eine kleines Panel links neben den USB-Anschlüssen. Öffnen Sie das Panel, indem Sie von unten mit einem **schmalen Schraubendreher** das Panel nach rechts wegschieben.
2. Schließen Sie ein Micro-USB-Kabel an den Mikrocontroller an.

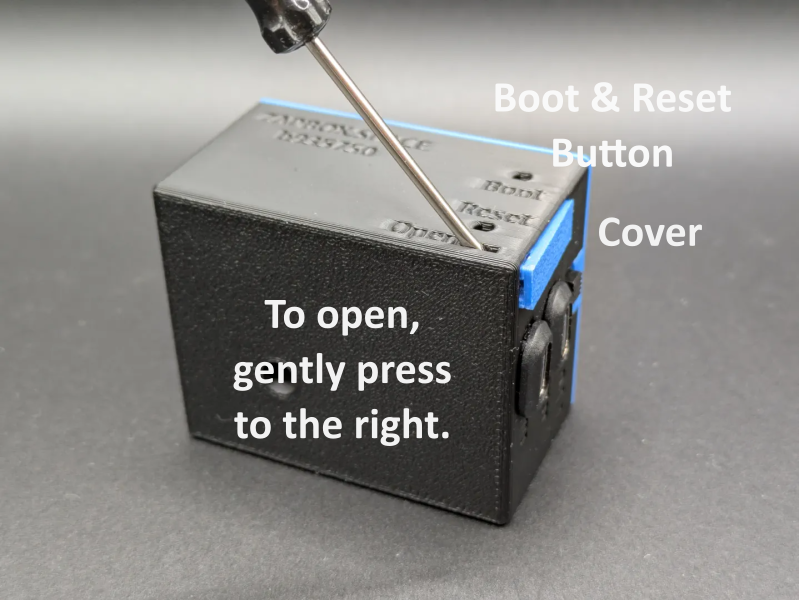
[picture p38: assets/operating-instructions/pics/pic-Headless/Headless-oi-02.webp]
Panel öffnen für Datenverbindung


*Bild 2: Panel öffnen für Datenverbindung*

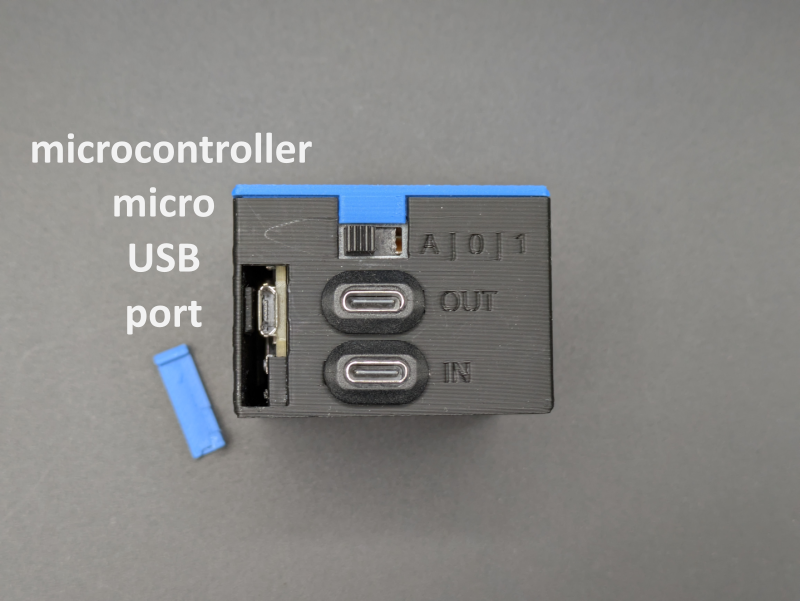
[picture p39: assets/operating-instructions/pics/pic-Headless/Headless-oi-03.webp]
Micro USB Port


*Bild 3: Micro USB Port*

> **Wichtiger Hinweis:** Der USB-Anschluss direkt am Mikrocontroller ist ausschließlich zum Flashen der Firmware und zur Übertragung von Konfigurationsparametern vorgesehen. Während des Flashvorgangs darf keine Last am Ausgang angeschlossen oder geschaltet werden, da dies zu Fehlfunktionen oder zur **Beschädigung des Mikrocontrollers** führen kann.
>
> Es wird daher empfohlen:
> - während der USB-Verbindung keine Last am Ausgang anzuschließen oder
> - den regulären **Power-IN-Eingang** zusätzlich an dieselbe Spannungsversorgung anzuschließen. Dadurch wird sichergestellt, dass der Strom für das Leistungsrelais nicht über den Mikrocontroller fließt und diesen überlastet.

---

### Ausgang - USB-C-Buchse (geschaltete 5V Spannung)

Die USB-Buchse wird über einen Relais-Schaltkontakt geschaltet. Die **Gesamtbelastung** der Buchsen sollte **3 A nicht überschreiten**.

---

## Bedienelemente

Die ZapBox Headless hat **kein Display**. Der Betriebszustand wird ausschließlich über die **Status-LED** (GPIO 21 (extern) / GPIO 2 (onboard)) und **Action-LED** (GPIO 13) signalisiert.

### Status-LED – Blinkmuster

| Muster | Bedeutung |
|---|---|
| 3× kurzes Blinken beim Start | Boot abgeschlossen |
| Schnelles Blinken | Verbindungsaufbau / Initialisierung |
| Langsames Blinken (1 Hz) | Config-Modus aktiv |
| Dauerlicht | Betriebsbereit, wartet auf Zahlung |
| Kurzes Ausschalten (300 ms) | Aktion gestartet – Relais/Servo ausgelöst |
| 200 ms an / 800 ms aus | NFC-Zahlung ausstehend (PENDING) |
| 2× kurzes Blinken | Zahlung erfolgreich |
| 3× kurzes Blinken | NFC-Timeout / Fehler |
| Sehr schnelles Blinken (10 Hz) | Sensor "vending machine" angesprochen |
| 1× Blinken (500 ms an/aus, 2 s Pause) | Fehlermuster 1: Kein WLAN |
| 2× Blinken (300 ms an/aus, 2 s Pause) | Fehlermuster 2: Kein Internet |
| 3× Blinken (250 ms an/aus, 2 s Pause) | Fehlermuster 3: Server nicht erreichbar |
| 4× Blinken (200 ms an/aus, 2 s Pause) | Fehlermuster 4: WebSocket-Verbindung fehlgeschlagen |
| Aus | Keine Spannungsversorgung |

### Bedientaster

| Funktion | Taster |
|---|---|
| Config-Modus aufrufen | BOOT-Taster mind. 5 Sek. gedrückt halten |
| Neustart | Reset-Taster |

### Dreifach-Schiebeschalter (AUTO / OFF / ON)

| Stellung | Funktion |
|---|---|
| **A** (AUTO) | Automatikbetrieb – Normalbetrieb |
| **0** (OFF) | Spannungsversorgung unterbrochen – Ausgang AUS |
| **1** (ON) | Ausgang (USB-C) dauerhaft EIN |

### Montagehalterung mit Schnapp-Arretierung

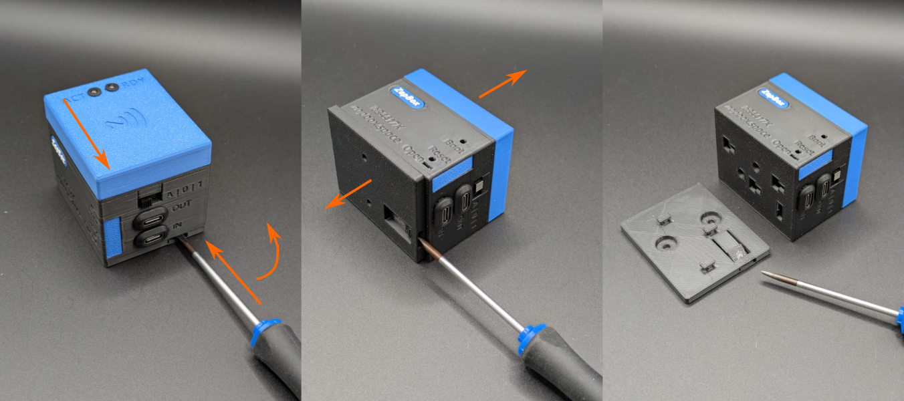
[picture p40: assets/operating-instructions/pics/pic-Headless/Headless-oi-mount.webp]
Lösen einer Montagehalter einer Headless mit NFC-Modul


*Bild 4: Lösen einer Montagehalter einer Headless mit NFC-Modul*

> **Hinweis:** Die ZapBox ist auf der Montagehalterung nur aufgeschoben und mit einem Schnappverschluss arretiert. Die Arretierung kann man mit einem flachen Schraubendreher lösen. Dazu den Schraubendreher vorsichtig in den Schlitz einschieben, leicht anheben und dabei den oberen Teil der ZapBox in Richtung des Schraubendrehers schieben. Die Verbindung sollte sich lösen und die ZapBox kann von der Montageplatte durch anheben gelöst werden.

---

## Einrichtung und Inbetriebnahme

Die ZapBox wird nach der Fertigung getestet und mit der aktuellen Firmware ausgeliefert - sie ist aber nicht parametriert. Die Software wird aktiv weiterentwickelt, daher ist es empfehlenswert, die ZapBox gleich zu Beginn einmal mit der neuesten Firmware zu bespielen und dann eine Parametrierung durchzuführen. Dafür gibt es einen komfortablen [**Web-Installer**](https://installer.zapbox.space/).

### Schritt 1: Firmware-Update
1. Öffnet das rechte Seitenpanel der Frontblende, wie oben unter "Seitenpanel öffnen" beschrieben.
2. Schließt die ZapBox an dem USB-C-Port mit einem Kabel an und verbindet es mit einem Computer.
3. Öffnet einen Chromium Browser, zum Beispiel Google Chrome, Microsoft Edge, Brave, Vivaldi, Opera oder [Helium](https://helium.computer/).

### Schritt 2: Parametrierung
1. Navigiert im Browser zur Web-Installer-Seite.
2. Folgt den Anweisungen auf der Seite, um die gewünschten Parameter wie `WiFi SSID`, `WiFi Passwort` und `Device Settings String` einzugeben.
3. Speichert die Einstellungen und startet die ZapBox neu.

> **Hinweis:** Während der Einrichtung sollte keine Last an den Ausgängen angeschlossen sein, um Fehlfunktionen oder Schäden am Mikrocontroller zu vermeiden.

Nach der Initialisierung leuchtet die Status-LED dauerhaft – die ZapBox ist betriebsbereit und wartet auf die erste Zahlung.

### Fehlerdiagnose und -behebung 

Die ZapBox zeigt Fehler über einen LED-Fehlerblinkcode an. Siehe dazu den vorherigen Kapitel *Status-LED – Blinkmuster*. Es gibt vier grundlegende Fehler, die priorisiert sind:

| Prio. | Fehlerart | Abkürzung | Erkennungsmethode | Beschreibung |
|---|---|---|---|---|
| 1 | **NO WIFI** | NW | WiFi-Verbindungsstatus | WiFi-Netzwerk nicht verbunden<br>-> Sind die WiFi-Daten korrekt?<br>-> Ist das WiFi-Signal zu schwach? |
| 2 | **NO INTERNET** | NI | HTTP-Check zu Google | Internetverbindung verloren<br>-> Ist das Internet erreichbar? |
| 3 | **NO SERVER** | NS | TCP-Port 443-Check | LNbits-Server nicht erreichbar<br>-> Ist die Server-Hardware ausgefallen?<br>-> Ist der Geräte-String korrekt? |
| 4 | **NO WEBSOCKET** | NWS | WebSocket-Verbindungsstatus | WebSocket-Protokoll-/Handshake-Fehler<br>-> Ist LNbits ausgefallen?<br>-> Ist der Geräte-String korrekt? |

Weitere aktuelle Informationen zu Fehlerbeschreibungen können auf der Web-Installer-Seite in den Kapiteln "Error Detection & Report" und "Troubleshoot" nachgelesen werden. 

---

## Option: NFC-Modul

Je nach Ausstattung ist auf der **Oberseite der ZapBox** ein NFC-Modul verbaut. Alternativ ist das Modul auch separat erhältlich. Die ZapBox unterstützt aktuell folgende Kartentypen:

- **Boltcards** (NTAG424)
- **LNURL-Withdraw** von NTAG21x (213 / 215 / 216)

Voraussetzung für die Funktion ist die LNbits [ZapBox Extension](https://github.com/AxelHamburch/zapbox_extension). Sie muss von dem LNbits Server unterstützt werden. 

---

## Technische Daten

| Eigenschaft | Wert |
|---|---|
| Versorgungsspannung | 5 V DC über USB-C |
| Maximaler Eingangsstrom | 5,0 A |
| Ausgangsleistung | max. 3,0 A (empfohlen) |
| Mikrocontroller | ESP32 Dev Module (WROOM-32) |
| Flash-Speicher | 4 MB |
| SRAM | 512 KB |
| Display | keines (Headless) |
| Statusanzeige | Status-LED / Action-LED |
| Temperaturbereich | 0–40 °C |
| Kommunikation | Wi-Fi (ESP32) |
| Relaiskanäle | 1 - Erweiterbar bis zu 12 (CH01–CH12) |
| Zahlungsprotokoll | Bitcoin Lightning Network |

---

## Sicherheitshinweise

- Betreiben Sie das Gerät ausschließlich mit der angegebenen Versorgungsspannung.
- Überschreiten Sie nicht die maximalen Strombelastungen der Ausgänge.
- Führen Sie keine Arbeiten an den Relaiskontakten unter Last durch.
- Das Gerät ist nicht für den Einsatz in feuchten oder nassen Umgebungen geeignet.
- Außerhalb der Reichweite von Kindern aufbewahren.

---

## Weiterführende Links

| Ressource | Link |
|---|---|
| Übersicht aller ZapBox-Modelle | https://zapbox.space/ |
| Web-Installer, Kurzübersicht & Fehlerbehebung | https://installer.zapbox.space/headless/ |
| Detaillierte Dokumentation (Parameter & Funktionen) | https://ereignishorizont.xyz/zapbox/ |
| GitHub-Repository (Software, E-Layouts, 3D-Druckdateien, Bedienungsanleitungen) | https://github.com/AxelHamburch/ZapBox |
| ZapBox Extension | https://github.com/AxelHamburch/zapbox_extension |
| LNbits | https://lnbits.com/ |

---

*Änderungen und Irrtümer vorbehalten. Stand: 2026*

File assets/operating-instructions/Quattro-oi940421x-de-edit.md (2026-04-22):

# ZapBox Quattro – Bedienungsanleitung

**Sprache:** Deutsch | **Version:** oi940421

---

## Inhaltsverzeichnis

1. [Einleitung](#einleitung)
2. [Ansichten](#ansichten)
3. [Anschlüsse](#anschlüsse)
4. [Bedienelemente](#bedienelemente)
5. [Einrichtung und Inbetriebnahme](#einrichtung-und-inbetriebnahme)
6. [Option: NFC-Modul](#option-nfc-modul)
7. [Technische Daten](#technische-daten)
8. [Sicherheitshinweise](#sicherheitshinweise)
9. [Weiterführende Links](#weiterführende-links)

---

## Einleitung

Die **ZapBox Quattro** ist ein elektronischer Schalter für Bitcoin-Lightning-Zahlungen. Mit einer Zahlung über das Lightning-Netzwerk lässt sich ein Ausgang schalten – ideal für Automaten, Präsentationen, Eventsteuerung und viele weitere Anwendungen.

### Grundausstattung

| Komponente | Beschreibung |
|---|---|
| Mikrocontroller | T-Display-S3 mit 1,9" LCD-Display |
| Frontpanel | Wahlweise mit 35° oder 90° Display Front (90° auch zum Einbau erhältlich) |
| Eingang | USB-C (Power IN) |
| Ausgänge CH1-CH4 | Vier Relaisausgänge, Schaltkontakte (NO/COM/NC) extern geführt |
| Bedienelement | LED-Button (volle ZapBox-Funktionalität) |
| Schalter 1 | 3-poliger Schiebeschalter (AUTO / OFF / ON) |
| Schalter 2 | 2-poliger Schiebeschalter (Invert Output) |
| Option BTC-Ticker | Aktivierbar über den Web Installer |
| Option Boardtaster | Zwei On-board-Mikrotaster |
| Option NFC-Modul | Für Bolt Cards (NTAG424 DNA) und Standard NTAG213/215/216 (mit LNURL-withdraw) |

---

## Ansichten

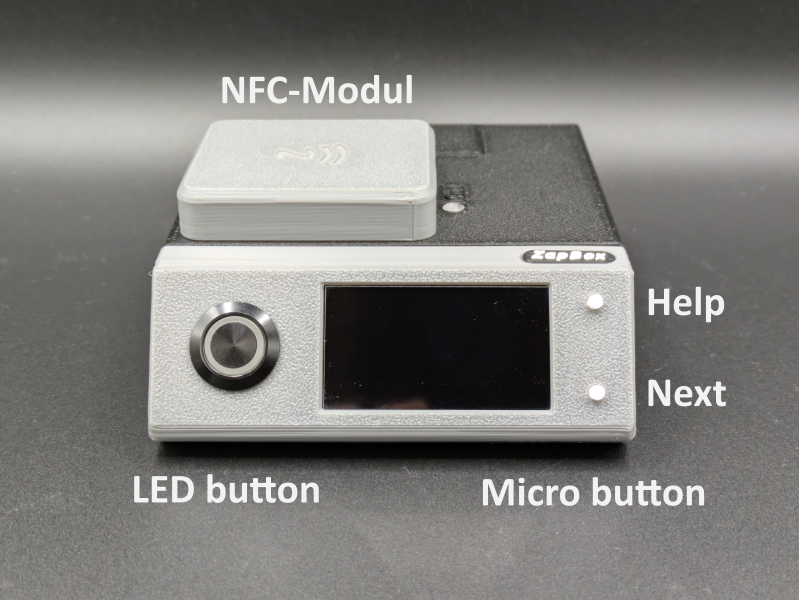
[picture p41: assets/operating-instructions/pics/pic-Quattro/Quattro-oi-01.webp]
Frontansicht


*Bild 1: Frontansicht*

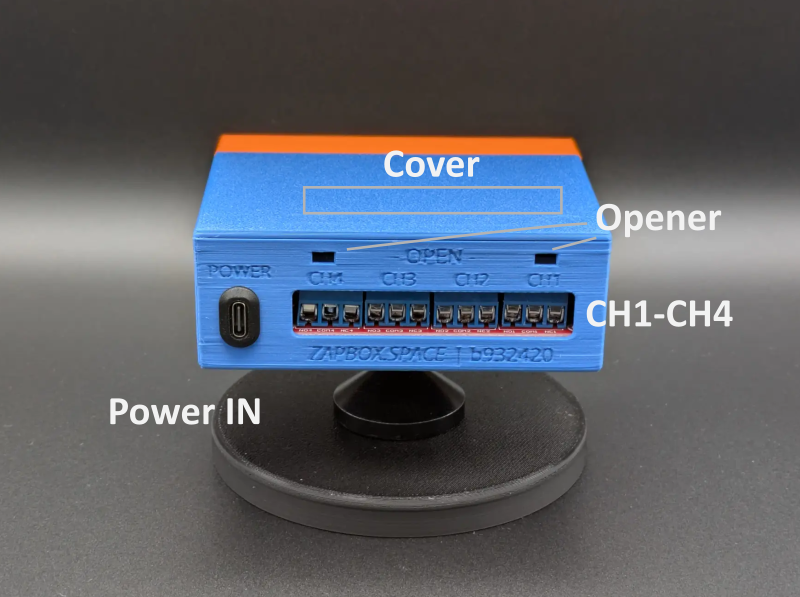
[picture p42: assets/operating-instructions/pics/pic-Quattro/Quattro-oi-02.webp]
Rückansicht


*Bild 2: Rückansicht*

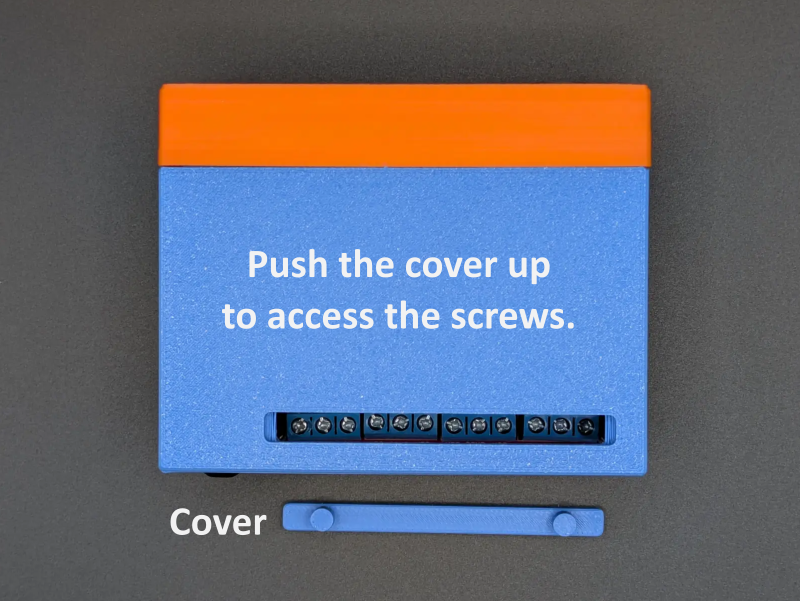
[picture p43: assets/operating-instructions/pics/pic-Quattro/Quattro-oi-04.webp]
Draufsicht


*Bild 3: Draufsicht*

---

## Anschlüsse

### Eingang - USB-C Buchse zur Spannungsversorgung (5V)

Versorgen Sie das Gerät über den Anschluss **Power IN** mit einem USB-C-Kabel mit **5 V DC (max. 5 A)**.

> **Hinweis:** Der USB-Power-Anschluss unterstützt keine automatische USB-C-Leistungsanforderung (kein USB-C Power Delivery). Einige USB-C-Ladegeräte oder Powermodule erkennen die ZapBox daher nicht als Verbraucher und liefern keinen Strom. Verwenden Sie in diesem Fall einen **USB-A-Ausgang** der Spannungsversorgung oder eine alternative 5-V-Stromquelle. Die maximale Stromstärke darf 3 A nicht überschreiten.

---

### Eingang - USB-C Buchse am Mikrocontroller (Datenzugang, hinter rechtem Seitenpanel)

Um Daten vom Gerät zu lesen oder zu übertragen, verbinden Sie die ZapBox mit einem Computer oder Laptop:

1. An der **rechten Seite der Frontblende** befindet sich eine kleine, verdeckte Klappe.
2. Öffnen Sie die Klappe, indem Sie von unten mit einem **schmalen Schraubendreher** die Klappe nach rechts wegschieben.
3. Schließen Sie ein USB-C-Kabel am darunter liegenden Anschluss des Mikrocontrollers an.

Panel öffnen und USB-C-Anschluss

*Bild: Panel öffnen und USB-C-Anschluss für Daten*

> **Wichtiger Hinweis:** Der USB-Anschluss direkt am Mikrocontroller ist ausschließlich zum Flashen der Firmware und zur Übertragung von Konfigurationsparametern vorgesehen. Während des Flashvorgangs darf keine Last am Ausgang angeschlossen oder geschaltet werden, da dies zu Fehlfunktionen oder zur **Beschädigung des Mikrocontrollers** führen kann.
>
> Es wird daher empfohlen:
> - während der USB-Verbindung keine Last am Ausgang anzuschließen oder
> - den regulären **Power-IN-Eingang** zusätzlich an dieselbe Spannungsversorgung anzuschließen. Dadurch wird sichergestellt, dass der Strom für das Leistungsrelais nicht über den Mikrocontroller fließt und diesen überlastet.

---

### Ausgänge CH1-CH4

 Der Quattro hat vier Relaisausgänge, die als Schaltkontakte (NO/COM/NC) von Außen erreichbar sind. Um an die Schrauben für die Kontaktlemmen zu kommen, muss man eine schmale Abdeckung heraushebeln. Dazu  einen kleinen Schlitzschraubendreher jeweils in die zwei Öffnungen oberhalb der Schaltkontakte einführen und die Abdeckung hochdrücken.

Die Kontakte der Relais sind für eine **maximale Strombelastung von 10 A** ausgelegt.

---

## Bedienelemente

Je nach Version verfügt die ZapBox neben dem **LED-Button** über zwei kleine **On-board-Mikrotaster**, die direkt mit dem Mikrocontroller verbunden sind. Alle Funktionen sind sowohl über den LED-Button als auch über die Mikrotaster erreichbar. Zusätzlich hat die ZapBox an der Unterseite des Frontpanels einen Reset-Taster und an der Seite zwei Schiebeschalter.

### Funktionsübersicht - Mikrotaster / LED-Button

| Funktion | Mikrotaster | LED-Button |
|---|---|---|
| Hilfe-Seite anzeigen | 1× HELP drücken | LED-Button mind. 2 Sek. gedrückt halten |
| Nächste Seite / Produktwechsel | 1× NEXT drücken | 1× LED-Button kurz drücken |
| REPORT-Seite anzeigen | 2× HELP drücken | LED-Button 3× schnell hintereinander drücken |
| Config-Modus aufrufen | NEXT mind. 5 Sek. gedrückt halten | 1× kurz drücken, dann mind. 5 Sek. gedrückt halten |

---

## Einrichtung und Inbetriebnahme

Die ZapBox wird nach der Fertigung getestet und mit der aktuellen Firmware ausgeliefert - sie ist aber nicht parametriert. Die Software wird aktiv weiterentwickelt, daher ist es empfehlenswert, die ZapBox gleich zu Beginn einmal mit der neuesten Firmware zu bespielen und dann eine Parametrierung durchzuführen. Dafür gibt es einen komfortablen [**Web-Installer**](https://installer.zapbox.space/).

### Schritt 1: Firmware-Update
1. Öffnet das rechte Seitenpanel der Frontblende, wie oben unter "Seitenpanel öffnen" beschrieben.
2. Schließt die ZapBox an dem USB-C-Port mit einem Kabel an und verbindet es mit einem Computer.
3. Öffnet einen Chromium Browser, zum Beispiel Google Chrome, Microsoft Edge, Brave, Vivaldi, Opera oder [Helium](https://helium.computer/).

### Schritt 2: Parametrierung
1. Navigiert im Browser zur Web-Installer-Seite.
2. Folgt den Anweisungen auf der Seite, um die gewünschten Parameter wie `WiFi SSID`, `WiFi Passwort` und `Device Settings String` einzugeben.
3. Speichert die Einstellungen und startet die ZapBox neu.

> **Hinweis:** Während der Einrichtung sollte keine Last an den Ausgängen angeschlossen sein, um Fehlfunktionen oder Schäden am Mikrocontroller zu vermeiden.

Die ZapBox wird nach der Initialisierung den QR-Code des Produkts anzeigen und ist bereit für die erste Zahlung und anschließende Schaltaktion.
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

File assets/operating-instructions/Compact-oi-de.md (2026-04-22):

# ZapBox Compact – Bedienungsanleitung

**Sprache:** Deutsch | **Version:** oi940284

---

## Inhaltsverzeichnis

1. [Übersicht](#übersicht)
2. [Ansichten](#ansichten)
3. [Anschlüsse](#anschlüsse)
4. [Bedienelemente](#bedienelemente)
5. [Einrichtung und Inbetriebnahme](#einrichtung-und-inbetriebnahme)
6. [Option: NFC-Modul](#option-nfc-modul)
7. [Technische Daten](#technische-daten)
8. [Sicherheitshinweise](#sicherheitshinweise)
9. [Weiterführende Links](#weiterführende-links)

---
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

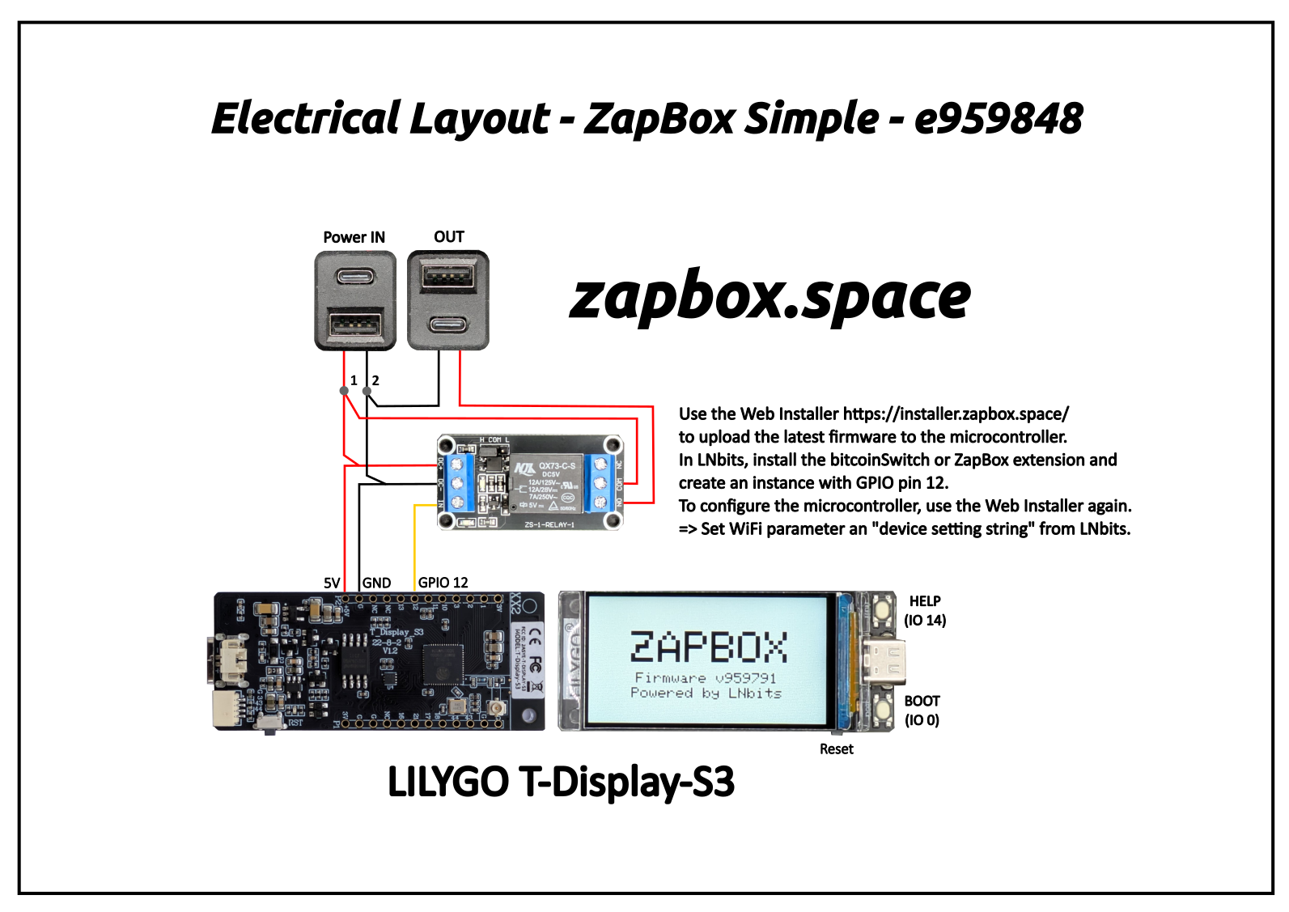
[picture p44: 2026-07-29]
installer/assets/E-Layout-ZapBox-T-Display-S3.webp

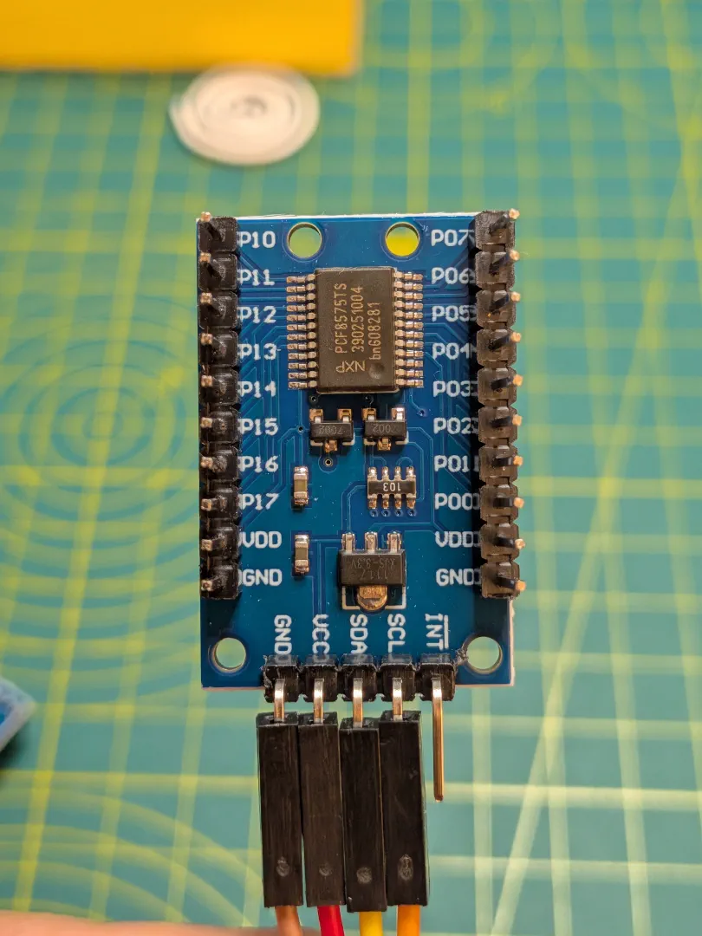
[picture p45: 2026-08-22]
installer/assets/IO-Expander-PCF8575-front.webp

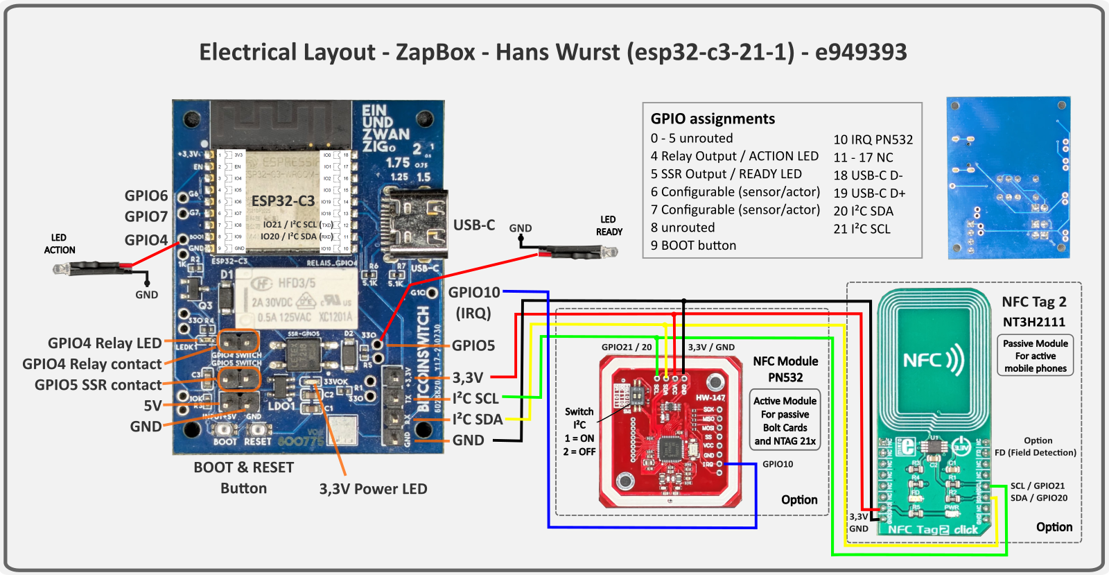
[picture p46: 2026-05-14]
installer/assets/esp32-c3-21-1.webp

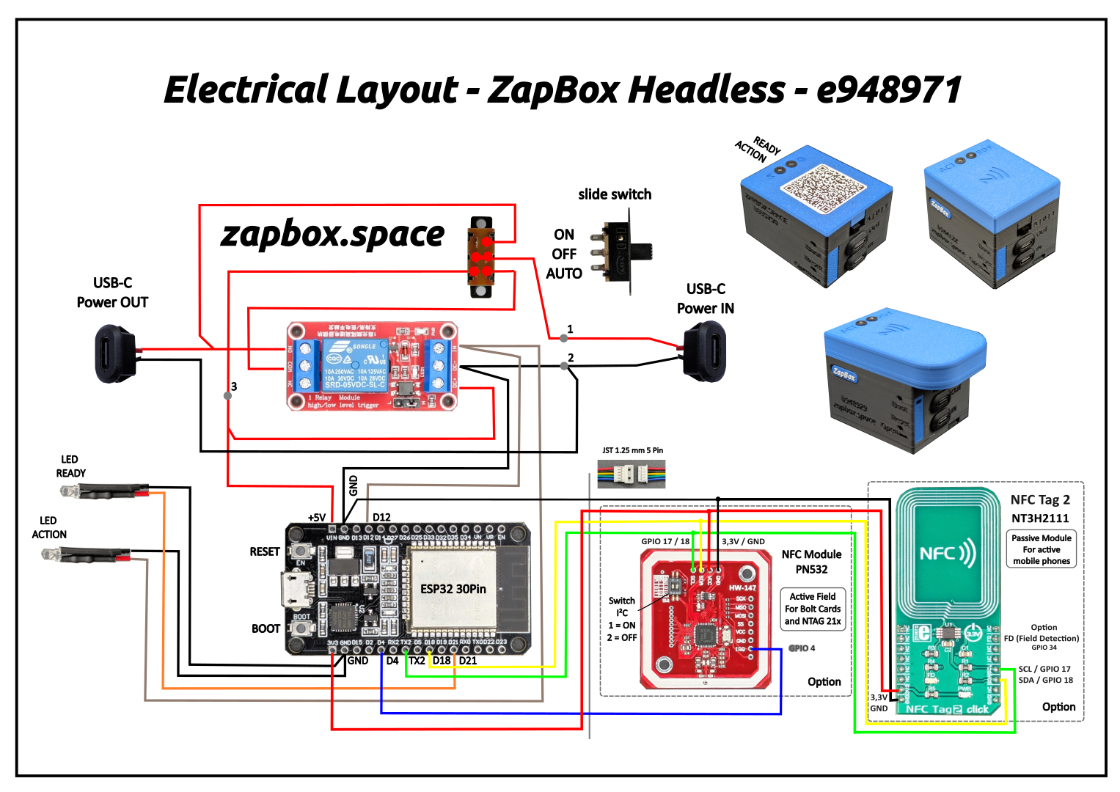
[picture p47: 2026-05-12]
installer/assets/E-Layout-ZapBox-Headless_normal.webp

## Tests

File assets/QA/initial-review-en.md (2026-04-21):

# Test Protocol for Initial Review

This document serves as the documentation for the initial inspection of the ZapBox, during which the tests performed and the parameters checked ensure the quality and functionality of the device. The ZapBox undergoes a comprehensive initial inspection at a test station, where the functions and parameters of the device are carefully examined to ensure quality and reliability.

---

## Device Identification

**ZapBox Type:** ____________________     **Serial Number:** ____________________     **Housing Version:** ____________________

**Base Color:** ___________     **Front:** ___________     **Button:** ___________     **NFC Module:** ___________

**Other / Special Features:** ________________________________________________________________

---

**Note:** For each ZapBox type, the relevant tests are marked with an "O". Each version has options. If not applicable, please mark with *n.a.* for *not available*.

**Abbreviations:**<br>
I = Current / U = Voltage / Term. = Terminal / GPIO = General-Purpose Input/Output

## Inspection of ZapBox with Display (T-Display-S3)

| Test Object \ Type | Compact | Duo | Quattro | ZapOMat | Servo | Hybrid |
|---|---|---|---|---|---|---|
| I-Input USB-C (idle)  | - | - | - | ___,____A | ___,____A | ___,____A |
| U-Output Term.1-2 (idle) | - | - | - | ___,____V | ___,____V | ___,____V |
| U-Output USB-A/C (switched) | ___,____V | ___,____V | - | - | ___,____V | ___,____V |
| Relay Channel 1 (GPIO Pin 12) | - | O | O | O | O | O |
| Relay Channel 2 (GPIO Pin 13) | - | O | O | O | - | O |
| Relay Channel 3 (GPIO Pin 10) | - | - | O | O | - | O |
| Relay Channel 4 (GPIO Pin 11) | - | - | O | O | O | O |
| Servo Channel 2 (GPIO Pin 13) | - | - | - | - | O | O |
| Servo Channel 3 (GPIO Pin 10) | - | - | - | - | O | O |
| Sensor Term.11 (GPIO Pin 2) | - | - | - | O | O | O |
| Display | O | O | O | O | O | O |
| OnBoard-Button | O | O | O | O | O | O |
| LED-Button | - | O | O | O | O | O |
| Side Cover | O | O | O | O | O | O |
| Snap-Fit Mounting | O | O | O | O | O | O |
| NFC Module | O | O | O | O | O | O |

---

## Inspection of ZapBox Headless (ESP32)

| Test Object | Headless | Headless Servo |
|---|---|---|
| I-Input USB-C (idle)  | ___,____A | ___,____A |
| U-Output Term.1-2 (idle) | - | ___,____V |
| U-Output Term.1-2 (switched) | - | ___,____V |
| U-Output USB-C (switched) | ___,____V | - |
| Relay Channel 3 - Term.3 - (GPIO Pin 12) | - | O |
| Servo Channel 3 - Term.3 - (GPIO Pin 12) | - | O |
| Sensor 1 - Term.4 - (GPIO Pin 22) | - | O |
| Sensor 2 - Term.5 - (GPIO Pin 23) | - | O |
| LED-READY | O | O |
| LED-ACTION | O | O |
| Side Cover | O | O |
| Snap-Fit Mounting | O | O |
| NFC Module | O | O |

---

## Notes

⚠️ **NFC Module:** The NFC module may function and still be defective. The error can be identified by the high current consumption of over 0.3A in idle mode.

---

## Inspection Result

**Inspection Result:** [ &nbsp; ] Passed / [ &nbsp; ] Failed

**Other Defects:** [ &nbsp; ] No / [ &nbsp; ] Yes — If yes, which: __________________________________________________________

 **Block Time ⛓️ :** ________________________     **Inspector 🖊 :** ________________________

---

*Best Quality - **[zapbox.space](https://zapbox.space)*** | Version: qa946083 | Language: English

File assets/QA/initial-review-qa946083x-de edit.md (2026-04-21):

# Testprotokoll zur Erstprüfung

Dieses Dokument dient der Dokumentation der Erstprüfung der ZapBox, bei der die durchgeführten Tests und überprüften Parameter die Qualität und Funktionalität des Geräts sicherstellen. Die ZapBox wird an einer Teststation einer umfassenden Erstprüfung unterzogen, bei der die Funktionen und Parameter des Geräts sorgfältig überprüft werden, um die Qualität und Zuverlässigkeit sicherzustellen.

---

## Geräteidentifikation

**ZapBox Typ:** _____________________     **Seriennummer:** _____________________     **Gehäuse Version:** _____________________

**Farbe Grundkörper:** ___________     **Front:** ___________     **Taster:** ___________     **NFC Modul:** ___________

**Sonstiges / Besonderheit:** ________________________________________________________________

---

**Hinweis:** Für den jeweiligen ZapBox Typ sind die relevanten Prüfungen mit einem "O" gekennzeichnet. Bei jeder Version gibt es Optionen. Bei nichtvorkommen bitte mit *n.a.* für *not available* kennzeichen.

**Abkürzungen:**<br>
I = Strom / U = Spannung / Kl. = Klemme / GPIO = General-Purpose Input/Output (universelle Ein-/Ausgabe) 

## Prüfung ZapBox mit Display (T-Display-S3)

| Prüfobjekt \ Typ | Compact | Duo | Quattro | ZapOMat | Servo | Hybrid |
|---|---|---|---|---|---|---|
| I-Eingang USB-C (ruhend)  | - | - | - | ___,____A | ___,____A | ___,____A |
| U-Ausgang Kl.1-2 (ruhend) | - | - | - | ___,____V | ___,____V | ___,____V |
| U-Ausgang USB-A/C (geschaltet) | ___,____V | ___,____V | - | - | ___,____V | ___,____V |
| Relais Kanal 1 (GPIO Pin 12) | - | O | O | O | O | O |
| Relais Kanal 2 (GPIO Pin 13) | - | O | O | O | - | O |
| Relais Kanal 3 (GPIO Pin 10) | - | - | O | O | - | O |
| Relais Kanal 4 (GPIO Pin 11) | - | - | O | O | O | O |
| Servo Kanal 2 (GPIO Pin 13) | - | - | - | - | O | O |
| Servo Kanal 3 (GPIO Pin 10) | - | - | - | - | O | O |
| Sensor Kl.11 (GPIO Pin 2) | - | - | - | O | O | O |
| Display | O | O | O | O | O | O |
| OnBoard-Button | O | O | O | O | O | O |
| LED-Button | - | O | O | O | O | O |
| Seitenabdeckung | O | O | O | O | O | O |
| Montage Schnappverschluss | O | O | O | O | O | O |
| NFC-Modul | O | O | O | O | O | O |

---

## Prüfung ZapBox Headless (ESP32)

| Prüfobjekt | Headless | Headless Servo |
|---|---|---|
| I-Eingang USB-C (ruhend)  | ___,____A | ___,____A |
| U-Ausgang Kl.1-2 (ruhend) | - | ___,____V |
| Ausgangsspannung Klemme 1-2 geschaltet | - | ___,____V |
| U-Ausgang USB-C (geschaltet) | ___,____V | - |
| Relais Kanal 3 - Kl.3 - (GPIO Pin 12) | - | O |
| Servo Kanal 3 - Kl.3 - (GPIO Pin 12) | - | O |
| Sensor 1 - Kl.4 - (GPIO Pin 22) | - | O |
| Sensor 2 - Kl.5 - (GPIO Pin 23) | - | O |
| LED-READY | O | O |
| LED-ACTION | O | O |
| Seitenabdeckung | O | O |
| Montage Schnappverschluss | O | O |
| NFC-Modul | O | O |

---

## Hinweise

⚠️ **NFC-Modul:** Das NFC-Modul kann funktionieren und trotzdem defekt sein. Den Fehler erkennt man an dem hohen Stromverbrauch über 0,3A im Ruhezustand.

---

## Prüfungsergebnis

**Ergebnis der Prüfung:** [ &nbsp; ] Bestanden / [ &nbsp; ] Nicht bestanden

**Sonstige Mängel:** [ &nbsp; ] Nein / [ &nbsp; ] Ja — Wenn ja, welche: _______________________________________________________

 **Blockzeit ⛓️ :** ________________________     **Prüfer 🖊 :** ________________________

---

*Beste Qualtiät - **[zapbox.space](https://zapbox.space)*** | Version: qa946083 | Sprache: Deutsch

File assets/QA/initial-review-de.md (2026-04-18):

# ZapBox - Erstprüfung

Die ZapBox wird an einer Teststation einer Erstprüfung unterzogen, bei der Funktionen und Parameter des Geräts zur Qualitätssicherung kontrolliert werden.

---

## Geräteidentifikation

**ZapBox Typ:** ________________________     **Seriennummer:** ________________________     **Gehäuse Version:** ________________________

**Farbe Grundkörper:** ___________     **Front:** ___________     **Taster:** ___________     **NFC Modul:** ___________

**Sonstiges / Besonderheit:** ________________________________________________________________

---

**Hinweis:** Für den jeweiligen ZapBox Typ sind die relevanten Prüfungen mit einem "O" gekennzeichnet. Bei jeder Version gibt es Optionen. Bei nichtvorkommen bitte mit *n.a.* für *not available* kennzeichen. 

## Prüfung ZapBox mit Display (T-Display-S3)

| Prüfobjekt \ Typ | Compact | Duo | Quattro | ZapOMat | Servo | Hybrid |
|---|---|---|---|---|---|---|
| Ausgangsspannung [V] Klemme 1-2 ruhend | - | - | - | ____,____V | ____,____V | ____,____V |
| Ausgangsspannung [V] Klemme 1-2 geschaltet | - | - | - | ____,____V | ____,____V | ____,____V |
| USB OUT Ausgangsspannung [V] geschaltet | ____,____V | ____,____V | - | ____,____V | ____,____V | ____,____V |
| CH1 Relais GPIO Pin 12 | - | O | O | O | O | O |
| CH2 Relais GPIO Pin 13 | - | O | O | O | - | O |
| CH3 Relais GPIO Pin 10 | - | - | O | O | - | O |
| CH4 Relais GPIO Pin 11 | - | - | O | O | O | O |
| CH2 Servo GPIO Pin 13 | - | - | - | - | O | O |
| CH3 Servo GPIO Pin 10 | - | - | - | - | O | O |
| Sensor GPIO Pin 2 | - | - | - | O | O | O |
| Funktion Display | O | O | O | O | O | O |
| Funktion OnBoard-Button | O | O | O | O | O | O |
| Funktion LED-Button | - | O | O | O | O | O |
| Panel Öffnung | O | O | O | O | O | O |
| Montage Schnappverschluss | O | O | O | O | O | O |
| NFC-Modul | O | O | O | O | O | O |

---

## Prüfung ZapBox Headless (ESP32)

| Prüfobjekt | Headless | Headless Servo |
|---|---|---|
| Ausgangsspannung Klemme 1-2 ruhend | - | ____,____V |
| Ausgangsspannung Klemme 1-2 geschaltet | - | ____,____V |
| USB OUT Ausgangsspannung geschaltet | ____,____V | - |
| Klemme 3 - Steuersignal Relais Pin 12 | - | O |
| Klemme 3 - Steuersignal Servo Pin 12 | - | O |
| Klemme 4 - Sensor 1 GPIO Pin 22 | - | O |
| Klemme 4 - Sensor 2 GPIO Pin 23 | - | O |
| Funktion LED-READY | O | O |
| Funktion LED-ACTION | O | O |
| Panel Öffnung | O | O |
| Montage Schnappverschluss | O | O |
| NFC-Modul | O | O |

---

## Hinweise

⚠️ **NFC-Modul:** Das NFC-Modul kann funktionieren und trotzdem defekt sein. Den Fehler erkennt man an dem hohen Stromverbrauch über 0,3A im Ruhezustand.

---

## Prüfungsergebnis

**Ergebnis der Prüfung:** [ &nbsp; ] Bestanden / [ &nbsp; ] Nicht bestanden

**Sonstige Mängel:** [ &nbsp; ] Nein / [ &nbsp; ] Ja — Wenn ja, welche: _________________________________________________________________

 **Blockzeit ⛓️ :** ________________________     **Prüfer 🖊 :** ________________________

---

*Beste Qualtiät - **[zapbox.space](https://zapbox.space)*** | Version: qa945642 | Sprache: Deutsch

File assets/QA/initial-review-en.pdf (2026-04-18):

# ZapBox - Initial Review

The ZapBox undergoes an initial review at a test station where device functions and parameters are checked for quality assurance.

## Device Identification

ZapBox Type: ________________________ Serial Number: ________________________ Housing Version: ________________________

Color Body: ___________ Front: ___________ Button: ___________ NFC Module: ___________

Miscellaneous / Special Features: ________________________________________________________________

Note: For each ZapBox type, relevant tests are marked with an "O". Each version has options. If not available, please mark with n.a. for not available.

## Testing ZapBox with Display (T-Display-S3)

Test Item \ Type | Compact Duo | Quattro ZapOMat Servo | Hybrid

Output Voltage [V] Terminal 1-
2 idle
- | - | - | ____,____V | ____,____V ____,____V

Output Voltage [V] Terminal 1-2 switched

- | - | - | ____,____V | ____,____V ____,____V

USB OUT Output Voltage [V]
switched
____,____V ____,____V - | ____,____V | ____,____V ____,____V
CH1 Relay GPIO Pin 12 | - | O | O | O | O | O
CH2 Relay GPIO Pin 13 | - | O | O | O | - | O
CH3 Relay GPIO Pin 10 | - | - | O | O | - | O
CH4 Relay GPIO Pin 11 | - | - | O | O | O | O
CH2 Servo GPIO Pin 13 | - | - | - | - | O | O
CH3 Servo GPIO Pin 10 | - | - | - | - | O | O
Sensor GPIO Pin 2 | - | - | - | O | O | O
Display Function | O | O | O | O | O | O
OnBoard-Button Function | O | O | O | O | O | O
LED-Button Function | - | O | O | O | O | O
Panel Opening | O | O | O | O | O | O
initial-review-qa945642-en.md | 2026-04-18

1 / 2

Test Item \ Type | Compact Duo | Quattro ZapOMat Servo | Hybrid
Assembly Snap Lock | O | O | O | O | O | O
NFC Module | O | O | O | O | O | O

## Testing ZapBox Headless (ESP32)

Test Item | Headless Headless Servo
Output Voltage Terminal 1-2 idle | - | ____,____V
Output Voltage Terminal 1-2 switched | - | ____,____V
USB OUT Output Voltage switched | | ____,____V -
Terminal 3 - Control Signal Relay Pin 12 - | O
Terminal 3 - Control Signal Servo Pin 12 - | O
Terminal 4 - Sensor 1 GPIO Pin 22 | - | O
Terminal 4 - Sensor 2 GPIO Pin 23 | - | O
LED-READY Function | O | O
LED-ACTION Function | O | O
Panel Opening | O | O
Assembly Snap Lock | O | O
NFC Module | O | O

## Notes

⚠️ NFC Module: The NFC module can work but still be defective. The error is identified by high power consumption above 0.3A in standby state.

## Test Result

Test Result: [ ] Passed / [ ] Failed

Other Defects: [ ] No / [ ] Yes — If yes, which ones: _________________________________________________________________

Block Time ⛓️ : ________________________ Tester 🖊 : ________________________

Best Quality - zapbox.space | Version: qa945642 | Language: English
initial-review-qa945642-en.md | 2026-04-18

2 / 2

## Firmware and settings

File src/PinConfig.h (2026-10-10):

#pragma once

/*ESP32S3 - LilyGo T-Display-S3 Pin Configuration*/

// Display - Backlight
#define PIN_LCD_BL 38          // LCD backlight control

// Display - 8-bit parallel data bus
#define PIN_LCD_D0 39
#define PIN_LCD_D1 40
#define PIN_LCD_D2 41
#define PIN_LCD_D3 42
#define PIN_LCD_D4 45
#define PIN_LCD_D5 46
#define PIN_LCD_D6 47
#define PIN_LCD_D7 48

// Power management
#define PIN_POWER_ON 15        // Power control pin

// Display - Control signals
#define PIN_LCD_RES 5          // LCD reset
#define PIN_LCD_CS 6           // LCD chip select
#define PIN_LCD_DC 7           // LCD data/command
#define PIN_LCD_WR 8           // LCD write
#define PIN_LCD_RD 9           // LCD read

// Physical buttons & battery
#define PIN_BUTTON_1 0         // BOOT button (left)
#define PIN_BUTTON_2 14        // HELP button (right)
#define PIN_BAT_VOLT 4         // Battery voltage ADC

// Vending machine light barrier (T-Display-S3 only)
#if ENABLE_DISPLAY
  #define PIN_LIGHT_BARRIER 2  // NPN light barrier input (INPUT_PULLUP, active LOW)
#else
  // Vending machine sensor inputs (ESP32 Dev headless only)
  #define PIN_SENSOR_1 22  // Sensor input 1 (INPUT_PULLUP, active LOW)
  #define PIN_SENSOR_2 23  // Sensor input 2 (INPUT_PULLUP, active LOW)
#endif

// I2C Bus (shared: Touch + NFC)
#define PIN_IIC_SCL 17         // I2C clock
#define PIN_IIC_SDA 18         // I2C data

// GPIO 3 / GPIO 34 — free expansion / sensor input / FD (Field Detection) from NT3H2111
// T-Display-S3: GPIO 3 (only free pin; INPUT_PULLUP supported)
// ESP32 Dev headless: GPIO 34 (input-only, no internal pull-up — pull-up must be provided externally,
//   e.g. on-board via NFC Tag 2 Click, or as discrete 10 kΩ to 3.3 V on bare NT3H2111 designs)
#if ENABLE_DISPLAY
  #define PIN_GPIO3 3
  #define PIN_GPIO3_MODE INPUT_PULLUP
#else
  #define PIN_GPIO3 34
  #define PIN_GPIO3_MODE INPUT   // GPIO 34-39 on classic ESP32: input-only, no internal pull-up!
#endif

// Touch controller (CST816S/CST328)
#define PIN_TOUCH_INT 16       // Touch interrupt
#if ENABLE_DISPLAY
  #define PIN_TOUCH_RES 21     // Touch reset (T-Display-S3)
#else
  #define PIN_TOUCH_RES -1     // Touch reset disabled for ESP32 Dev (GPIO 21 used for LED)
#endif

// NFC Reader (PN532) - Optional
// GPIO 1 is safe on ESP32-S3 (T-Display-S3), but equals UART0 TX on classic ESP32 Dev.
#if ENABLE_DISPLAY
  #define PIN_NFC_IRQ 1   // T-Display-S3 (ESP32-S3): GPIO 1 is free (no UART conflict)
#else
  #define PIN_NFC_IRQ 4   // ESP32 Dev (classic ESP32): GPIO 1 = UART0 TX → use GPIO 4
#endif

// ─────────────────────────────────────────────────────────────
// Relay channels (Multi-Channel-Control)
//
// CH01 and CH02 are identical on both boards:
//   CH01 → GPIO 12  (default / single-mode)
//   CH02 → GPIO 13
//
// CH03 / CH04 differ per board:
//   T-Display-S3 (ESP32-S3, ENABLE_DISPLAY=1):
//     CH03 → GPIO 10  │ ESP32-S3: GPIO 10/11 are available breakout pins
//     CH04 → GPIO 11  │ GPIO 11 also used for channel-4 ambient-light sync
//   ESP32 Dev / headless (ENABLE_DISPLAY=0):
//     CH03 → GPIO 14  │ GPIO 10/11 are internal flash on ESP32-WROOM-32
//     CH04 → GPIO 16  │ and must NOT be used as output!
//
// Headless ESP32 Dev only – 8 additional channels (total: 12):
//   CH05 → GPIO 19
//   CH06 → GPIO 22
//   CH07 → GPIO 23
//   CH08 → GPIO 25
//   CH09 → GPIO 26
//   CH10 → GPIO 27
//   CH11 → GPIO 32
//   CH12 → GPIO 33
// ─────────────────────────────────────────────────────────────
#define PIN_RELAY_CH01 12
#define PIN_RELAY_CH02 13

#if ENABLE_DISPLAY
  // T-Display-S3 (ESP32-S3): GPIO 10/11 are valid breakout pins
  #define PIN_RELAY_CH03 10
  #define PIN_RELAY_CH04 11  // also ambient-light sync
#else
  // ESP32 Dev Module (classic ESP32-WROOM-32):
  // GPIO 6-11 are connected to internal SPI flash – NEVER use as output!
  #define PIN_RELAY_CH03 14
  #define PIN_RELAY_CH04 16
#endif

#if !ENABLE_DISPLAY && !defined(BOARD_ESP32C3_21_1)
  // Extra relay channels available on ESP32 Dev Module (no display pins consumed)
  #define PIN_RELAY_CH05 19
  #define PIN_RELAY_CH06 22
  #define PIN_RELAY_CH07 23
  #define PIN_RELAY_CH08 25
  #define PIN_RELAY_CH09 26
  #define PIN_RELAY_CH10 27
  #define PIN_RELAY_CH11 32
  #define PIN_RELAY_CH12 33
  #define RELAY_CHANNEL_MAX 12
  // Ordered list of all relay GPIOs (indices 0-11 = CH01-CH12)
  static const int RELAY_CHANNEL_PINS[RELAY_CHANNEL_MAX] = {
    PIN_RELAY_CH01, PIN_RELAY_CH02, PIN_RELAY_CH03, PIN_RELAY_CH04,
    PIN_RELAY_CH05, PIN_RELAY_CH06, PIN_RELAY_CH07, PIN_RELAY_CH08,
    PIN_RELAY_CH09, PIN_RELAY_CH10, PIN_RELAY_CH11, PIN_RELAY_CH12
  };
#elif !defined(BOARD_JC3248W535C) && !defined(BOARD_ESP32C3_21_1)
  #define RELAY_CHANNEL_MAX 4
  static const int RELAY_CHANNEL_PINS[RELAY_CHANNEL_MAX] = {
    PIN_RELAY_CH01, PIN_RELAY_CH02, PIN_RELAY_CH03, PIN_RELAY_CH04
  };
#endif
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

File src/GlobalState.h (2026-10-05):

#ifndef GLOBAL_STATE_H
#define GLOBAL_STATE_H

#include <Arduino.h>
#include "PinConfig.h"   // RELAY_CHANNEL_PINS — flex channels are looked up by channel, not by GPIO

/**
 * @file GlobalState.h
 * @brief Centralized global state management with organized data structures
 * 
 * Organizes all global variables into semantic groups to improve code clarity,
 * maintainability, and reduce the cognitive load of tracking scattered state.
 */

// ============================================================================
// WIFI & NETWORK CONFIGURATION
// ============================================================================

struct WifiConfig {
  String ssid = "";
  String wifiPassword = "";
  String switchStr = "";
  static constexpr const char* lightningPrefix = "lightning:";
};

extern WifiConfig wifiConfig;

// ============================================================================
// DISPLAY & THEME SETTINGS
// ============================================================================

struct DisplayConfig {
  String orientation = "h";  // "h" for horizontal, "v" for vertical
  String theme = "black-white";
};

extern DisplayConfig displayConfig;

// ============================================================================
// LIGHTNING PAYMENT CONFIGURATION
// ============================================================================

struct LightningConfig {
  char lightning[640] = "";     // Main Lightning URL/QR code (BOLT11 invoices with route hints can exceed 400 chars)
  String thresholdKey = "";     // Optional threshold mode key
  String thresholdAmount = "";  // Threshold amount in sats
  String thresholdPin = "";     // GPIO pin for threshold
  String thresholdTime = "";    // Threshold timeout
  String thresholdLnurl = "";   // Alternative LNURL for threshold mode
};

extern LightningConfig lightningConfig;

// ============================================================================
// POWER MANAGEMENT & SCREENSAVER
// ============================================================================

struct PowerConfig {
  String screensaver = "off";   // Screensaver mode: "off", "on", etc.
  String deepSleep = "off";     // Deep sleep mode: "off", "freeze", "light"
  String activationTime = "5";  // Screensaver activation time in minutes
  unsigned long activationTimeoutMs = 0;  // Screensaver timeout in milliseconds
  String deepSleepTime = "30";  // Deep sleep activation time in minutes
  unsigned long deepSleepTimeoutMs = 0;   // Deep sleep timeout in milliseconds
  unsigned long lastWakeUpTime = 0;  // Track when device woke up from screensaver
};

extern PowerConfig powerConfig;

// ============================================================================
// EXTERNAL LED BUTTON STATE & CONFIGURATION
// ============================================================================

struct ExternalButtonState {
  bool pressed = false;
  bool holdActionFired = false;
  uint8_t clickCount = 0;
  unsigned long sequenceStart = 0;
  unsigned long pressStartTime = 0;
  unsigned long lastChange = 0;
  bool enabled = false; // Whether external button is enabled (replaces onboard buttons)
};

struct ExternalButtonConfig {
  static constexpr unsigned long DEBOUNCE_MS = 50;
  static constexpr unsigned long TRIPLE_WINDOW_MS = 2000;
  static constexpr unsigned long HELP_HOLD_MS = 2000;
  static constexpr unsigned long CONFIG_HOLD_MS = 3000;
  static constexpr unsigned long CONFIG_EXIT_GUARD_MS = 2000; // Minimum time before button/touch can exit config
};

extern ExternalButtonState externalButtonState;

// ============================================================================
// SPECIAL MODES & WAVEFORM CONTROL
// ============================================================================

struct SpecialModeConfig {
  String mode = "standard";  // "standard", "frequency", "brightness", etc.
  float frequency = 1.0;     // Frequency multiplier for waveform mode
  float dutyCycleRatio = 1.0; // Duty cycle for PWM modes
};

extern SpecialModeConfig specialModeConfig;

// ============================================================================
// MULTI-CHANNEL CONTROL & BTC TICKER
// ============================================================================

struct MultiChannelConfig {
  String mode = "off";        // "off", "duo", "quattro", "servo"
  String btcTickerMode = "off"; // "off", "always", "selecting"
  volatile bool btcTickerActive = false; // volatile for multi-threaded WebSocket access
  volatile int currentProduct = -1;    // -1 = selection screen, 1-4 = product number (volatile for multi-context access)
};

extern MultiChannelConfig multiChannelConfig;

// ============================================================================
// VENDING MACHINE SENSOR INPUTS
// T-Display-S3: Single sensor on GPIO 2
// ESP32 Dev Headless: Two sensors on GPIO 22 and GPIO 23
// ============================================================================

struct LightBarrierConfig {
  // Sensor 1 — GPIO 2 (T-Display-S3) or GPIO 22 (headless)
  String mode = "no";  // "no" (disabled), "yes" (stop action on trigger), "monitor" (block next payment), "level" (level monitoring), "relay" (relay output synced with pin 12)
  bool enabled = false;         // true when mode == "yes"
  bool monitoring = false;      // true when mode == "monitor"
  bool levelMonitoring = false; // true when mode == "level"
  bool relayOutput = false;     // true when mode == "relay" (headless: GPIO acts as relay output, synced with pin 12)
  bool blocked = false;         // runtime: product output currently blocked (monitor mode)
  bool binEmpty = false;        // runtime: supply bin is empty (level monitoring mode)
  unsigned long minActionTime = 2000; // Minimum 2 seconds before light barrier can stop action

  // Sensor 2 — GPIO 23 (headless only)
  String mode2 = "no";
  bool enabled2 = false;
  bool monitoring2 = false;
  bool levelMonitoring2 = false;
  bool relayOutput2 = false;    // true when mode2 == "relay"
  bool blocked2 = false;
  bool binEmpty2 = false;

  // Sensor 3 — JC3248W535C only (GPIO 6 / CH05). The Touch 3.5 exposes all three
  // ADC1-capable pins (GPIO 5/6/7) as sensor-capable channels; this is the third.
  String mode3 = "no";
  bool enabled3 = false;
  bool monitoring3 = false;
  bool levelMonitoring3 = false;
  bool relayOutput3 = false;    // true when mode3 == "relay"
  bool blocked3 = false;
  bool binEmpty3 = false;

  bool isActive() const { return enabled || monitoring || levelMonitoring; }
  bool isActive2() const { return enabled2 || monitoring2 || levelMonitoring2; }
  bool isActive3() const { return enabled3 || monitoring3 || levelMonitoring3; }
  bool isAnyActive() const { return isActive() || isActive2() || isActive3(); }
  // True when any sensor condition blocks payments
  bool isAnyBlocking() const { return blocked || blocked2 || blocked3 || binEmpty || binEmpty2 || binEmpty3; }
};
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

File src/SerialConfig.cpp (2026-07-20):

#include <Arduino.h>
#include <WiFi.h>
#include "FS.h"
#include "FFat.h"
#include "SerialConfig.h"
#ifdef BOARD_JC3248W535C
  #include "TouchAXS15231B.h"
#else
  #include "TouchCST816S.h"
#endif
#include "DeviceState.h"
#include "GlobalState.h"
#include "PinConfig.h"
#include "UI.h"   // ledSetOn() — all LED pin writes go through the PWM wrapper

// Global reference to touch controller (set from main.cpp)
void* touchControllerPtr = nullptr;
extern unsigned long configModeStartTime;
extern StateManager deviceState;

// Check if NEXT, HELP, or EXTERNAL button is pressed to exit config mode
static bool checkButtonExit() {
    // Static variables to track previous button states
    static int prevNextState = HIGH;
    static int prevHelpState = HIGH;
    static int prevExtState = HIGH;
    static bool initialized = false;
    
    // Initialize button states on first call (during guard period)
    // This prevents triggering exit if buttons are already pressed when config mode starts
    if (!initialized) {
        prevNextState = digitalRead(PIN_BUTTON_1);
        #if !defined(BOARD_ESP32C3_21_1) && !defined(BOARD_JC3248W535C)
        // PIN_BUTTON_2 = GPIO14 = SPI Flash IO1 on ESP32-C3 — never read as GPIO.
        // On JC3248W535C, GPIO14 = channel CH01 (no physical HELP button;
        // config is exited via touch) — reading it as a button causes spurious
        // floating-pin exits and a config-mode boot loop.
        prevHelpState = digitalRead(PIN_BUTTON_2);
        #endif
        #ifdef PIN_LED_BUTTON_SW
        prevExtState = digitalRead(PIN_LED_BUTTON_SW);
        #else
        prevExtState = HIGH; // Not available on this board
        #endif
        initialized = true;
    }
    
    // Only check after guard period
    if (configModeStartTime == 0 || (millis() - configModeStartTime) < ExternalButtonConfig::CONFIG_EXIT_GUARD_MS) {
        return false;
    }
    
    // Check NEXT button (PIN_BUTTON_1)
    int nextState = digitalRead(PIN_BUTTON_1);
    if (prevNextState == HIGH && nextState == LOW) { // Negative edge (button pressed)
        Serial.println("[CONFIG] NEXT button pressed - exiting config mode");
        prevNextState = nextState;
        initialized = false; // Reset for next config mode session
        return true;
    }
    prevNextState = nextState;
    
    // Check HELP button (PIN_BUTTON_2)
    // On ESP32-C3-21-1, PIN_BUTTON_2 = GPIO14 = SPI Flash IO1 — skip to avoid spurious exits.
    // On JC3248W535C, PIN_BUTTON_2 defaults to GPIO14 = channel CH01 (no HELP button) —
    // the floating pin produces phantom HIGH→LOW edges and a config-mode boot loop. Exit via touch.
    #if !defined(BOARD_ESP32C3_21_1) && !defined(BOARD_JC3248W535C)
    int helpState = digitalRead(PIN_BUTTON_2);
    if (prevHelpState == HIGH && helpState == LOW) { // Negative edge (button pressed)
        Serial.println("[CONFIG] HELP button pressed - exiting config mode");
        prevHelpState = helpState;
        initialized = false; // Reset for next config mode session
        return true;
    }
    prevHelpState = helpState;
    #endif
    
    // Check EXTERNAL button (PIN_LED_BUTTON_SW) - only if available
    #ifdef PIN_LED_BUTTON_SW
    int extState = digitalRead(PIN_LED_BUTTON_SW);
    if (prevExtState == HIGH && extState == LOW) { // Negative edge (button pressed)
        Serial.println("[CONFIG] EXTERNAL button pressed - exiting config mode");
        prevExtState = extState;
        initialized = false; // Reset for next config mode session
        return true;
    }
    prevExtState = extState;
    #endif
    
    return false;
}

void configOverSerialPort(String wifiSSID, String wifiPass, bool hasExistingData)
{
    executeConfig(wifiSSID, wifiPass, hasExistingData);
}

// Helper: Send a line over serial with USB CDC pacing.
// ESP32-S3 native USB CDC sends at USB speed, not limited by baud rate.
// Without pacing, rapid Serial.println() calls overflow the browser's
// Web Serial API buffer and bytes get silently dropped.
static void serialPrint(const String &msg) {
    Serial.print(msg);
    Serial.flush();
    delay(15);
}

static void serialPrintln(const String &msg) {
    Serial.println(msg);
    Serial.flush();
    delay(15);
}

static void serialPrintln() {
    Serial.println();
    Serial.flush();
    delay(15);
}

// Helper: Send long string over serial with USB CDC pacing (chunked).
// Used for any output longer than ~64 bytes to prevent buffer overflow.
static void serialWriteChunked(const String &msg) {
    const int chunkSize = 64;
    for (unsigned int i = 0; i < msg.length(); i += chunkSize) {
        unsigned int endPos = min(i + (unsigned int)chunkSize, (unsigned int)msg.length());
        Serial.write(msg.c_str() + i, endPos - i);
        Serial.flush();
        delay(15);
    }
}
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

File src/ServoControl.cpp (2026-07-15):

#include "ServoControl.h"
#include "GlobalState.h"
#include "PinConfig.h"
#include "Log.h"
#include <ESP32Servo.h>

static Servo servo1;  // Display: Pin 13 positional | Headless: Pin 12 (servo180)
static Servo servo2;  // Display: Pin 10 continuous  | Headless: Pin 12 (servo360)
static bool servo1Attached = false;
static bool servo2Attached = false;

#ifdef BOARD_ESP32C3_21_1
static Servo servo_flex6;  // C3 GPIO6 flex channel
static Servo servo_flex7;  // C3 GPIO7 flex channel
static bool servoFlex6Attached = false;
static bool servoFlex7Attached = false;
#endif

#ifdef BOARD_JC3248W535C
// Touch 3.5 multi-channel: one servo per flex channel (CH01..CH06).
// Index 0..5 maps to GPIO 14, 15, 16, 5, 6, 7 (== RELAY_CHANNEL_PINS).
static const int T35_SERVO_GPIO[6] = {14, 15, 16, 5, 6, 7};
static Servo t35Servos[6];
static bool  t35Attached[6] = {false, false, false, false, false, false};
static int t35ServoIdx(int gpio) {
  for (int i = 0; i < 6; i++) if (T35_SERVO_GPIO[i] == gpio) return i;
  return -1;
}
#endif

// Slowly sweep a servo from one angle to another over the given duration.
// If duration_ms == 0, jump directly to target (native servo speed).
static void slowSweep(Servo &srv, int fromAngle, int toAngle, int duration_ms) {
  int steps = abs(toAngle - fromAngle);
  if (steps == 0) {
    srv.write(toAngle);
    return;
  }
  if (duration_ms <= 0) {
    srv.write(toAngle);
    return;
  }
  int stepDelay = duration_ms / steps;
  if (stepDelay < 1) stepDelay = 1;
  int dir = (toAngle > fromAngle) ? 1 : -1;
  for (int pos = fromAngle; pos != toAngle; pos += dir) {
    srv.write(pos);
    vTaskDelay(pdMS_TO_TICKS(stepDelay));
  }
  srv.write(toAngle);
}

void initServos() {
#if ENABLE_DISPLAY
  // Display version: servo1 on Pin 13, servo2 on Pin 10
  if (servoConfig.servo1Active()) {
    servo1.attach(13);
    servo1Attached = true;
    servo1.write(servoConfig.servo1Start);
    LOG_INFO("Servo", String("Servo 1 (positional) attached to Pin 13, start: ") + String(servoConfig.servo1Start) + "°");
  }
  if (servoConfig.servo2Active()) {
    servo2.attach(10);
    servo2Attached = true;
    servo2.write(90); // 90 = stop for continuous servo
    LOG_INFO("Servo", String("Servo 2 (continuous) attached to Pin 10, stopped (90)"));
  }
#else
  // Headless version: servo on Pin 12 (single-pin mode)
  if (multiChannelConfig.mode == "servo180" && servoConfig.servo1Active()) {
    servo1.attach(12);
    servo1Attached = true;
    servo1.write(servoConfig.servo1Start);
    LOG_INFO("Servo", String("180° Servo attached to Pin 12, start: ") + String(servoConfig.servo1Start) + "°");
  } else if (multiChannelConfig.mode == "servo360" && servoConfig.servo2Active()) {
    servo2.attach(12);
    servo2Attached = true;
    servo2.write(90); // 90 = stop for continuous servo
    LOG_INFO("Servo", "360° Servo attached to Pin 12, stopped (90)");
  }
#endif
#ifdef BOARD_ESP32C3_21_1
  if (c3FlexConfig.gpio6Servo180 || c3FlexConfig.gpio6Servo360) {
    servo_flex6.attach(PIN_FLEX_CH01);
    servoFlex6Attached = true;
    servo_flex6.write(c3FlexConfig.gpio6Servo180 ? c3FlexConfig.gpio6S180Start : 90);
    LOG_INFO("Servo", String("Flex GPIO6 servo attached, start: ") +
             (c3FlexConfig.gpio6Servo180 ? String(c3FlexConfig.gpio6S180Start) + "°" : String("90 (stop)")));
  }
  if (c3FlexConfig.gpio7Servo180 || c3FlexConfig.gpio7Servo360) {
    servo_flex7.attach(PIN_FLEX_CH02);
    servoFlex7Attached = true;
    servo_flex7.write(c3FlexConfig.gpio7Servo180 ? c3FlexConfig.gpio7S180Start : 90);
    LOG_INFO("Servo", String("Flex GPIO7 servo attached, start: ") +
             (c3FlexConfig.gpio7Servo180 ? String(c3FlexConfig.gpio7S180Start) + "°" : String("90 (stop)")));
  }
#endif
#ifdef BOARD_JC3248W535C
  for (int i = 0; i < 6; i++) {
    const T35AmbientConfig::ServoChannel& sc = t35AmbientConfig.servo[i];
    if (!sc.isServo()) continue;
    t35Servos[i].attach(T35_SERVO_GPIO[i]);
    t35Attached[i] = true;
    t35Servos[i].write(sc.servo180 ? sc.s180Start : 90); // 90 = stop for continuous
    LOG_INFO("Servo", String("T35 GPIO") + T35_SERVO_GPIO[i] + " servo attached, start: " +
             (sc.servo180 ? String(sc.s180Start) + "°" : String("90 (stop)")));
  }
#endif
}

void activateServo(int servoPin) {
#ifdef BOARD_JC3248W535C
  {
    int i = t35ServoIdx(servoPin);
    if (i >= 0 && t35Attached[i]) {
      const T35AmbientConfig::ServoChannel& sc = t35AmbientConfig.servo[i];
      if (sc.servo180) {
        LOG_INFO("Servo", String("T35 GPIO") + servoPin + " 180°: " + sc.s180Start + "° → " + sc.s180End + "°");
        slowSweep(t35Servos[i], sc.s180Start, sc.s180End, sc.s180Duration);
      } else if (sc.servo360) {
        LOG_INFO("Servo", String("T35 GPIO") + servoPin + " 360°: speed " + sc.s360Speed);
        t35Servos[i].write(sc.s360Speed);
        if (sc.s360Duration > 0) {
          vTaskDelay(pdMS_TO_TICKS(sc.s360Duration));
          t35Servos[i].write(90); // stop
        }
      }
      return;
    }
  }
#endif
#ifdef BOARD_ESP32C3_21_1
  if (servoPin == PIN_FLEX_CH01 && servoFlex6Attached) {
    if (c3FlexConfig.gpio6Servo180) {
      LOG_INFO("Servo", String("Flex GPIO6 180°: ") + c3FlexConfig.gpio6S180Start + "° → " + c3FlexConfig.gpio6S180End + "°");
      slowSweep(servo_flex6, c3FlexConfig.gpio6S180Start, c3FlexConfig.gpio6S180End, c3FlexConfig.gpio6S180Duration);
    } else if (c3FlexConfig.gpio6Servo360) {
      LOG_INFO("Servo", String("Flex GPIO6 360°: speed ") + c3FlexConfig.gpio6S360Speed);
      servo_flex6.write(c3FlexConfig.gpio6S360Speed);
      if (c3FlexConfig.gpio6S360Duration > 0) {
        vTaskDelay(pdMS_TO_TICKS(c3FlexConfig.gpio6S360Duration));
        servo_flex6.write(90);
      }
    }
    return;
  }
  if (servoPin == PIN_FLEX_CH02 && servoFlex7Attached) {
    if (c3FlexConfig.gpio7Servo180) {
      LOG_INFO("Servo", String("Flex GPIO7 180°: ") + c3FlexConfig.gpio7S180Start + "° → " + c3FlexConfig.gpio7S180End + "°");
      slowSweep(servo_flex7, c3FlexConfig.gpio7S180Start, c3FlexConfig.gpio7S180End, c3FlexConfig.gpio7S180Duration);
    } else if (c3FlexConfig.gpio7Servo360) {
      LOG_INFO("Servo", String("Flex GPIO7 360°: speed ") + c3FlexConfig.gpio7S360Speed);
      servo_flex7.write(c3FlexConfig.gpio7S360Speed);
      if (c3FlexConfig.gpio7S360Duration > 0) {
        vTaskDelay(pdMS_TO_TICKS(c3FlexConfig.gpio7S360Duration));
        servo_flex7.write(90);
      }
    }
    return;
  }
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

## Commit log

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2025-12-13 feat: Add core dump support and fix config mode after deep sleep (v927737)
    Major improvements:
    - Add 64KB core dump partition for crash analysis
    - Enable esp32_exception_decoder for better error diagnostics
    - Fix USB-Serial reinitialization after light deep sleep
    - Fix config mode detection after wake from deep sleep
    - Improve web installer connection handling
    Core Dump:
    - Added coredump partition (64KB) to partitions_16mb.csv
    - Enabled CONFIG_ESP32_ENABLE_COREDUMP_TO_FLASH
    - Added CORE_DEBUG_LEVEL=3 for detailed logging
    - Added esp32_exception_decoder monitor filter
    Deep Sleep Fixes:
    - Reinitialize USB-CDC (Serial.end/begin) after light sleep wake-up
    - Send multiple [CONFIG_MODE_ENTER] si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
    [partitions_16mb.csv]
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2025-12-21 feat: proactive error detection and optimized startup sequence
    MAJOR IMPROVEMENTS:
    - Proactive error display: Show error screens BEFORE testing connections
    - Connection confirmation tracking: New flags (wifiConfirmed, internetConfirmed, serverConfirmed, websocketConfirmed)
    - Optimized startup: All connections establish in parallel during startup screens
    - Early exit: QR code displays as soon as all connections confirmed (typically 10-15s)
    STARTUP SEQUENCE:
    - Phase 1: Startup screen (6 seconds) - WiFi connects in background
    - Phase 2: Initialization screen (up to 19 seconds) - All checks run in parallel
    - Maximum total time: 25 seconds if connections take longer
    - Immediate QR code display w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
    [Display.cpp]
2025-12-22 feat: Implement touch functionality for T-Display-S3 Touch variant
    - Created custom TouchCST816S driver for CST816S/CST328 touch controller
    - Added product selection screen with navigation arrows
    - Implemented comprehensive touch detection:
    * Swipe gestures in all directions (UP/DOWN/LEFT/RIGHT)
    * Single tap detection on left/right screen sides
    * Long press detection on screen sides
    * Touch button support (physical button on touch panel)
    - Fixed coordinate mapping for display rotation (touch Y display X)
    - Added automatic product selection screen (shows after 5 seconds)
    - Touch integration with WiFi recovery and error handling
    - All touch events trigger navigation back to QR screen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
    [Display.cpp, TouchCST816S.cpp]
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2025-12-23 feat: Code consolidation and currency symbol support
    - Consolidated duplicate screen functions:
    * switchedOnScreen + specialModeScreen -> actionTimeScreen
    * showQRScreen/showSpecialModeQRScreen now use showProductQRScreen with backend labels
    - Added currency symbol text replacement (€->EUR, \$->USD, ->GBP, etc.)
    - Smaller font for third line (currency display)
    - Cleaner product selection text (SELECT PRODUCT)
    - Fixed GFXFF font crash by keeping -DSMOOTH_FONT=1 flag
    - All modes (Normal, Special, Multi-Control) now use backend product labels
    [Display.cpp]
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2025-12-23 feat: Touch button implementation with Help/Report/Config modes
    - Implemented virtual touch button in bottom area (Y > 305) for all display orientations
    - Click detection logic: 1x = Help (after 1s), 2x = Report (after 1s), 3x = wait, 4x = Config
    - Touch button works independently from main display touch handling
    - Hardware-based touch coordinates (don't rotate with display)
    - 100ms debounce to prevent accidental double-clicks
    - Help Mode: 3 screens with early abort on second click
    - Report Mode: Optimized timing (2s first screen, 1s per additional screen)
    - Config Mode: 60 second timeout before auto-return
    - Fixed button area filtering in product navigation (both selection and QR screens)
    -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
    [SerialConfig.cpp]
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2025-12-23 feat: Add Bitcoin Ticker feature
    - Replace product selection screen with Bitcoin ticker (currentProduct=0)
    - Display BTC/USD price from CoinGecko API
    - Display current Bitcoin block height from mempool.space
    - Auto-update every 2 minutes (120 seconds)
    - Works with Multi-Channel-Control mode (Duo/Quattro)
    - Touch navigation: Swipe to navigate between ticker and products
    - Vertical & horizontal layout support
    - Initial fetch during setup
    - Non-blocking updates in main loop
    [Display.cpp]
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2025-12-23 Fix display refresh issues and race conditions in multi-channel mode
    - Fix screen overlay/ghosting when switching from BTC ticker to product screens
    - Add volatile qualifier to btcTickerActive and currentProduct for multi-task safety
    - Prevent concurrent display updates by adding proper checks and delays
    - Fix 'Pin 0' bug by capturing currentProduct value before switch-case
    - Add default case fallback to Pin 12 for invalid product numbers
    - Preserve currentProduct value when returning to BTC ticker screen
    - Optimize display rendering order: fillScreen -> drawQRCode -> UI elements
    - Explicitly clear QR code area in btctickerScreen to prevent ghosting
    [Display.cpp]
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2025-12-25 Fix inverse orientation positioning: vi no shift, hi shift +5px, HELP away from QR, mirror text for hi
    [Display.cpp]
2025-12-25 Fix inverse orientation label sides: swap HELP/NEXT positions for true 180° rotation
    [Display.cpp]
2025-12-25 Fix QR screen button positions: hi left side, vi top (matching physical button locations)
    [Display.cpp]
2025-12-25 Revert QR code to 3x3 size; apply vi/hi button positioning to btctickerScreen
    [Display.cpp]
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2025-12-26 Add PN532 NFC reader support with I2C integration
    - Add NFC pin definitions (GPIO 1 IRQ, GPIO 2 RST) to PinConfig.h
    - Create NFCPN532 class with full I2C implementation
    - Implement IRQ-based card detection for low power consumption
    - Add hardware reset capability for reliable operation
    - Share I2C bus with Touch controller (no GPIO conflicts)
    - Support ISO14443A cards (Mifare, NTAG, etc.)
    - Document pin configuration and relay/LED button assignments
    - Update README.md with NFC setup instructions and wiring diagram
    - Add complete GPIO pin map with comments and free pins list
    [NFCPN532.cpp, PinConfig.h]
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2025-12-26 Fix HELP text orientation for inverted displays - Corrected HELP button position on vertical inverse (vi) screens to display at top where touch button is located - Fixed HELP letter order on horizont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
    [Display.cpp]
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2025-12-28 fix: resolve remaining globals after struct migration
    - Use lightningConfig.lightning in Display QR generation
    - Remove duplicated EXTERNAL_* constants in main.cpp
    - Confirm build passes (pio run)
    [Display.cpp]
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2025-12-28 fix: define GRACE_PERIOD_MS locally in UI.cpp
    Fixed linker error by defining GRACE_PERIOD_MS in UI.cpp
    instead of using extern declaration.
    [UI.cpp]
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2025-12-28 punkt5: extract Navigation module (handleTouchButton, navigateToNextProduct)
    - Created src/Navigation.h/.cpp with touch interaction and product navigation
    - handleTouchButton(): Multi-click detection, screensaver wake, config exit
    - navigateToNextProduct(): Multi-channel product navigation and ticker rotation
    - Fixed: Restored showHelp() function that was accidentally deleted
    - Fixed: Changed TOUCH_DOUBLE_CLICK_MS to non-const for extern linkage
    - main.cpp: 2265 1990 lines (-275 lines, 12.1%)
    - Combined Punkt 4+5: 2537 1990 lines (-547 lines, 21.6%)
    - Total refactoring: 3099 1990 lines (-1109 lines, 35.8%)
    [Navigation.cpp]
2025-12-28 Fix single-mode "ON - when selecting" behavior
    - Respect installer-configured btcTickerMode in single mode (no forced "always")
    - Setup: show BTC ticker immediately only for single "always"; otherwise show QR (incl. special-mode)
    - First loop: decide initial screen by mode (single selecting/off -> QR, single always -> ticker)
    - Integrate special-mode QR handling in single path
    - Keep Duo/Quattro logic unchanged; timeouts (BTCTICKER_TIMEOUT) apply as intended
    Files: src/main.cpp
    [UI.cpp]
2025-12-28 Refactor: extract initial-screen selection and power saving checks
    - Added `showInitialScreenAfterConnections()` to centralize startup screen choice (threshold, single, duo/quattro)
    - Added `handlePowerSavingChecks()` to encapsulate screensaver/deep sleep logic
    - Replaced large first-loop block with a single call; moved power-saving blocks out of `loop()`
    - Minor includes and externs in UI.cpp; updated UI.h prototypes
    Files: src/UI.h, src/UI.cpp, src/main.cpp
    [UI.cpp]
2025-12-28 Refactor: unify LNURL + QR update via ensureQrForPin(pin)
    - Added `ensureQrForPin(int)` in Payment to wrap `generateLNURL` + `updateLightningQR`
    - Replaced repeated call pairs in UI, Navigation, main with the new helper
    - Safety: helper skips update on empty LNURL
    Files: src/Payment.h, src/Payment.cpp, src/UI.cpp, src/Navigation.cpp, src/main.cpp
    [Navigation.cpp, UI.cpp]
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2025-12-28 refactor(Network.cpp): Replace Serial.println/printf with LOG_* macros for structured logging
    - Integrate Log.h helper for consistent network logging
    - Add context tags: WebSocket, Network
    - Log levels: DEBUG for events/data, INFO for status, WARN/ERROR for issues
    - Replace 14 Serial calls in webSocketEvent, checkInternetConnectivity, checkServerReachability, checkAndReconnectWiFi
    - Improves log readability with timestamps and compile-time filtering
    [Network.cpp]
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2025-12-28 refactor(Navigation.cpp): Replace Serial.println/printf with LOG_* macros for navigation and touch logging
    - Integrate Log.h helper for consistent navigation and touch event logging
    - Add context tags: Navigation, Touch
    - Log levels: INFO for significant events (navigation, clicks, mode transitions), DEBUG for detailed interactions
    - Replace 21 Serial calls across navigateToNextProduct() and handleTouchButton()
    - Improves clarity of product navigation, touch button interactions, and config mode transitions
    [Navigation.cpp]
2025-12-28 refactor(UI.cpp): Replace Serial.println/printf with LOG_* macros for UI/power-saving logging
    - Integrate Log.h helper for consistent UI and power-saving logging
    - Add context tags: Wake, Display, DeepSleep, WakeUp
    - Log levels: DEBUG for status details, INFO for important transitions, WARN for issues
    - Replace 15 Serial calls in wakeFromPowerSavingMode, redrawQRScreen, handlePowerSavingChecks
    - Improves visibility of screen transitions and power-saving activation/wake-up sequences
    [UI.cpp]
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2025-12-28 perf(API.cpp): Parallelize Bitcoin data requests (CoinGecko + Mempool) for ~50% faster fetch
    - Create separate FreeRTOS tasks for CoinGecko price and Mempool block height
    - Both requests run on Core 0 in parallel instead of sequentially
    - Reduce BTC data fetch time from ~3-4s to ~2s
    - Add timeout mechanism (6s max) to prevent hanging if either API is slow
    - Improves startup time and ticker responsiveness when currency/labels are updated
    - Uses xTaskCreatePinnedToCore for reliable task management on dual-core ESP32-S3
    [API.cpp]
2025-12-28 fix(API.cpp): Increase FreeRTOS task stack size from 4KB to 12KB for HTTPS/SSL handling
    Stack overflow was triggered when tasks attempted SSL handshake and JSON parsing.
    mbedTLS cryptography operations require more stack space than initially allocated.
    Increased both fetchCoinGeckoTask and fetchMempoolTask stack sizes to 12288 bytes.
    [API.cpp]
2025-12-28 fix(API.cpp): Change parallel BTC fetch to sequential to prevent SSL memory allocation failures
    Both HTTPS requests were competing for SSL context memory, causing allocation failures.
    Changed to sequential execution: CoinGecko first (4s timeout), 200ms cleanup delay, then Mempool (4s timeout).
    This prevents simultaneous SSL handshakes and memory pressure on the heap.
    [API.cpp]
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2025-12-28 fix(startup): Improve Internet connectivity detection with stabilization delay and retry logic
    Problem: Internet check was happening immediately after WiFi connect, before DNS/DHCP/gateway fully configured.
    This caused false "no internet" errors even though network was actually functional.
    Solutions:
    1. Add 2+ second stabilization delay after WiFi connects before Internet check
    2. Internet check now retries 3 times (500ms between attempts) to handle DNS propagation
    3. Track WiFi connection time to ensure proper sequencing
    This prevents premature Internet failure detection while WiFi stack is still initializing.
    [Network.cpp]
2025-12-28 refactor: Replace pin-label if-else chains with array-based system
    Eliminates 3x if-else chains for pin-to-label mapping (12, 13, 10, 11 GPIO pins).
    - GlobalState.h: ProductLabels now uses String[4] array instead of 4 separate members
    - Index mapping: 0=pin10, 1=pin11, 2=pin12, 3=pin13
    - Added getPinIndex(pin) helper function for conversion
    - API.cpp: Clear and assign labels using array indices (eliminates 4x if-else)
    - Navigation.cpp: Simplified product->pin mapping and label lookup
    - UI.cpp: Cleaner label retrieval using array-based access
    - Display.cpp: Updated showQRScreen() and showSpecialModeQRScreen()
    Benefits:
    - Eliminates repetitive if-else chains (3 instances)
    - More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
    [API.cpp, Display.cpp, GlobalState.h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]
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2025-12-28 fix(API): Add 30s backoff delay for failed label fetch retries to prevent SSL memory exhaustion
    Critical Bug: When label fetching failed (SSL -32512), the system retried immediately
    in every loop iteration (~150ms), causing heap exhaustion and continuous SSL failures.
    Solution:
    - Added LABEL_RETRY_BACKOFF (30 seconds) between retry attempts
    - Track lastLabelFetchAttempt timestamp
    - Skip retry attempts if backoff period not elapsed
    - Prevents rapid-fire HTTPS requests that exhaust SSL context memory
    This fixes the SSL memory allocation failure loop observed in production.
    [API.cpp]
2025-12-28 fix(API): Add BTC fetch backoff and aggressive SSL cleanup to prevent ticker errors
    - Add 30s backoff between failed BTC fetch attempts (same as labels)
    - Track lastBtcFetchAttempt timestamp in fetchBitcoinData()
    - Enforce BTC_RETRY_BACKOFF check in updateBitcoinTicker()
    - Add 100ms cleanup delay in both CoinGecko and Mempool task functions
    - Add error logging for HTTP failures (SSL -32512 debug)
    - Prevents repeated SSL allocation failures when ticker is running
    - BTC ticker now auto-recovers after 30s if fetch fails
    [API.cpp]
2025-12-28 refactor(API): Simplify BTC fetch - remove task-based parallelization, use sequential execution
    - Remove fetchCoinGeckoTask() and fetchMempoolTask() (80+ lines)
    - Remove parallelBtcData struct and task handles
    - Replace with direct sequential HTTP requests (~40 lines)
    - Keep 30s backoff mechanism for SSL stability
    - Consolidate lastLabelFetchAttempt and lastBtcFetchAttempt to single lastFetchAttempt
    - Consolidate LABEL_RETRY_BACKOFF and BTC_RETRY_BACKOFF to single RETRY_BACKOFF
    - Reduces API.cpp from 330 to 223 lines (-33% code reduction)
    - No functional change - same stability, much cleaner code
    - Performance impact minimal: +2s fetch time, still well within 5min intervals
    [API.cpp]
2025-12-28 feat: Add NEXT/HELP button exit from Config mode + UX improvements
    **Config Mode Exit Enhancement:**
    - Add button exit support from Config mode (NEXT/HELP buttons)
    - Implement direct GPIO polling in SerialConfig loop (OneButton was blocking)
    - 2-second guard period before buttons become active
    - Negative edge detection (button press, not release) for immediate response
    - Touch exit remains functional as before
    **Auto-Config Entry:**
    - Automatically enter Config mode after startup if no SSID is configured
    - Skip initialization wait when SSID is missing/invalid
    - Improves first-time setup UX (no need to manually trigger Config)
    **Display Improvements:**
    - BTC Ticker vertical inverse (vi): Sh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
    [Display.cpp, SerialConfig.cpp]
2025-12-28 feat: Add ZAPBOX theme with inverted Product QR colors
    - Add 'zapbox' theme preset (Yellow foreground on Black background)
    - Implement drawQRCodeWithColors() helper for custom color rendering
    - Modified showProductQRScreen() to invert colors (Black on Yellow) exclusively for ZAPBOX theme
    - Other screens retain YELLOW & BLACK colors as default
    - Updated installer with ZAPBOX theme option in dropdown
    - All tests pass, device boots and displays correctly
    [Display.cpp]
2025-12-29 fix(display): Stabilize TFT refresh with safeFillScreen after screen clears
    - Add safeFillScreen(color) wrapper with 10ms delay
    - Use on action, thank you, threshold QR, product QR, product selection screens
    - Helps prevent horizontal stripes/black screen during frequent switches (ticker always mode)
    [Display.cpp]
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2025-12-29 Fix BTC Ticker ALWAYS mode bugs for Single and Duo modes
    Bug Fixes:
    1. Single Mode ALWAYS: Fixed timeout not returning to ticker
    - Timer was incorrectly reset in Navigation.cpp
    - Changed logic: Timer starts when showing QR, resets to 0 when showing ticker
    - Now correctly returns to ticker after PRODUCT_TIMEOUT (60s)
    2. Duo Mode ALWAYS: Fixed timeout loop causing display issues
    - Timer was not reset after timeout triggered
    - Caused ticker to be redrawn continuously every loop
    - Now resets timer to 0 after showing ticker via timeout
    3. ZAPBOX Theme Display Corruption: Fixed horizontal stripes and color artifacts
    - Display controller couldn't handle rapid color inversions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
    [Display.cpp, Navigation.cpp]
2025-12-31 feat: Improve PRODUCT_TIMEOUT behavior and reduce BTC ticker flicker
    - Reset PRODUCT_TIMEOUT on all user interactions (touch, NEXT, HELP, external button)
    - Pause timer during ACTION TIME and restart after thank-you screen
    - Force QR display (not ticker) after payment in ALWAYS mode with full timeout
    - Enhance display stability for ZapBox theme with triple-clear (20ms+10ms+5ms delays)
    - Add partial update for BTC ticker values to reduce flicker during auto-refresh
    - New updateBtctickerValues() function updates only price/sats/block without full redraw
    Fixes:
    - QR screen now stays visible for full PRODUCT_TIMEOUT after user interaction
    - No premature ticker display after payment completion
    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
    [API.cpp, Display.cpp]
2025-12-31 feat: Change zapbox theme color from yellow (0xD600) to gold (0xFEA0)
    - Updated theme definition color value
    - Updated inverted QR code background color
    - Gold color has more stable bit pattern (full red channel, higher green)
    - May improve display controller stability compared to previous yellow
    [Display.cpp]
2025-12-31 fix: Improve navigation timing and Bitcoin data retry logic
    Navigation.cpp:
    - Fix race condition when navigating from PRODUCT_SELECTION screen
    - Reset timer immediately when starting from product selection to prevent timeout
    API.cpp:
    - Add intelligent retry logic for failed Bitcoin data fetches
    - Reduce retry interval from 5 minutes to 1 minute when errors detected
    - Track error state (btcDataHasError) to trigger faster retries
    - Normal 5-minute update interval when data loads successfully
    [API.cpp, Navigation.cpp]
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2026-01-13 Fix: LED-Button (GPIO 42) Config-Modus Exit + Feature: LED-Button aktiv Option
    Bug-Fix:
    - Externer LED-Button kann jetzt den Config-Modus beenden
    - SerialConfig.cpp: checkButtonExit() prüft nun auch PIN_LED_BUTTON_SW
    - Negative Flanke (HIGH→LOW) beendet Config-Modus nach 2s Guard-Periode
    - Vorher konnte Button nur Config-Modus starten, aber nicht beenden
    Neues Feature:
    - "Separate LED button" Option im Web-Installer hinzugefügt (Index 20)
    - Dropdown mit "No" (Standard) und "Yes" Auswahl
    - Bei Aktivierung werden HELP und NEXT Labels auf allen Displays ausgeblendet
    - Verhalten entspricht Touch-Version (zeigt nur relevante Bedienelemente)
    - Config-Wert wird persistent gespeichert und beim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
    [Display.cpp, GlobalState.h, SerialConfig.cpp]
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2026-01-19 Fix ESP32 Dev headless LED control and conditional compilation
    Critical fixes for ESP32 Dev Module (headless) support:
    1. Fix conditional compilation for ENABLE_DISPLAY
    - Changed #ifdef to #if for ENABLE_DISPLAY checks
    - Problem: -DENABLE_DISPLAY=0 was still "defined" causing wrong branch
    - Files: PinConfig.h, main.cpp
    - Result: GPIO pins now correctly selected per board type
    2. Fix GPIO pin conflicts and LED control
    - ESP32 Dev: PIN_TOUCH_RES=-1, PIN_LED_BUTTON_LED=21 (no button)
    - T-Display-S3: PIN_TOUCH_RES=21, PIN_LED_BUTTON_LED=43/44 (with button)
    - Resolved GPIO 227 error (was using wrong pin definition)
    - LED now correctly turns ON when ready, OFF during erro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
    [partitions_4mb.csv]
2026-01-20 Fix: Display rotation bug for inverted themes + Web installer improvements
    **Display Rotation Bug Fix:**
    - Fixed sporadic display rotation issue where screen appeared upside-down and mirrored
    - Issue occurred specifically with 'BTC ORANGE & BLACK (inv. QR)' and 'ZAPBOX' themes
    - Root cause: Multiple consecutive fillScreen() calls reset display rotation
    - Solution: Added ensureCorrectRotation() helper function called after each critical display operation
    - Function now called at:
    1. Start of showProductQRScreen() (before any drawing)
    2. After each fillScreen() in color inversion sequence
    3. After QR code drawing (before text rendering)
    - Prevents ST7789 display controller from losing ro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
    [Display.cpp]
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2026-01-21 Fix WebSocket stability and implement payment queue system
    Critical fixes for WebSocket disconnections during rapid trigger events:
    1. Fixed tight loop causing CPU blocking
    - Added vTaskDelay(10ms) in main payment wait loop
    - Prevents thousands of loop iterations per second
    - Allows WebSocket.loop() to execute properly
    2. Replaced blocking delays with non-blocking implementation
    - All delay() calls replaced with while-loops that call webSocket.loop()
    - Affects: processThresholdPayment(), processNormalPayment(), executeSpecialMode()
    - Keeps WebSocket connection alive during GPIO switching
    - Server continues receiving pings/pongs during payment processing
    3. Implemented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
    [GlobalState.cpp, GlobalState.h, Network.cpp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]
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2026-02-11 Headless: NULL-Pointer Protection + Boot-Indikator + CP2102 Hardware-Warnung
    - NULL-Pointer-Checks: Alle JSON-Config-Felder (maRoot3-20) werden auf nullptr geprüft, verhindert Abstürze bei korrupten/unvollständigen config.json
    - Boot-Indikator: 3 schnelles LED-Blinken in setup() visualisiert ESP32-Resets
    - Config-Exit-Fix: cleanRestart() durch ESP.restart() ersetzt nach Funktionsentfernung
    - CP2102-Warnung: Web-Installer dokumentiert CP2102 USB-to-Serial Reset-Verhalten im Troubleshoot-Bereich
    Grund-Ursache: CP2102 sendet DTR/RTS-Signale bei Connect/Disconnect triggert ESP32 Reset (Hardware-Limitation, kein Software-Bug)
    Workaround: ESP32 nach Web-Installer-Nutzung komplett vom Strom t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
    [Navigation.cpp, UI.cpp]
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2026-02-16 Split web installer into T-Display-S3 and headless versions with status indicators
    - Create separate headless installer at installer/headless/index.html
    - Remove display-specific options from headless (theme, orientation, screensaver, deep sleep, BTC ticker, multi-channel, light barrier, QR format, LED button)
    - Add metallic gray gradient background for headless version
    - Add favicon_headless.webp for visual distinction
    - Implement connection status indicator (green/gray)
    - Implement config mode status indicator (green/gray)
    - Add cross-links between both installer versions
    - Update "Load config values" instructions
    - Fix /file-read bug: Send prefix only once to prevent JSON corruption
    - Bot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
    [SerialConfig.cpp]
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
